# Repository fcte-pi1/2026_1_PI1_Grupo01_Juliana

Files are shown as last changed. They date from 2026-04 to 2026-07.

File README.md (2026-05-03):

# 2026.1_PI1_Grupo1_Juliana

## 🐭 Projeto Integrador 1 – Micromouse Autônomo

Desenvolvimento de um robô autônomo do tipo Micromouse capaz de explorar e resolver labirintos de diferentes dimensões (4×4, 8×8 e 16×16). O projeto é desenvolvido por equipes multidisciplinares organizadas em quatro subgrupos: **Software**, **Eletrônica**, **Estrutura** e **Energia**.

A documentação técnica completa — incluindo escopo, cronograma, orçamento e diagramas — está disponível na pasta [docs/](https://github.com/fcte-pi1/2026_1_PI1_Grupo01_Juliana/tree/main/docs).

---

## 🧩 Visão Geral
O Micromouse é um robô de pequeno porte que navega de forma completamente autônoma por um labirinto, sem intervenção humana durante a execução. O sistema é composto por:

### 💻 Software
- Definição da arquitetura de software embarcado e web.
- Implementação do controle de locomoção (PID) e navegação autônoma nos 3 labirintos.
- Sistema web de telemetria com exibição em tempo real e histórico de corridas.

### 🔌 Eletrônica
- Seleção e integração de sensores e atuadores.  
- Desenvolvimento do esquemático e PCB.  
- Calibração e testes de circuitos.  

### 🔩 Estrutura
- Projeto do chassi e layout do veículo.  
- Montagem e fixações definitivas.  
- Integração física dos módulos de hardware e energia.  

### ⚡ Energia
- Análise de consumo energético.  
- Dimensionamento da bateria.  
- Validação com testes reais.  

---

## 📁 Estrutura do projeto
```
2026_1_PI1_Grupo01_Juliana/
│
├── docs/        # Documentação técnica, relatórios e diagramas
├── hw/          # Esquemáticos, PCB e arquivos de eletrônica
├── mec/         # Arquivos de CAD e projeto mecânico
├── src/         # Código-fonte do software embarcado e web
|
├── CONTRIBUTING.MD
└── README.md
```

---

## 🤝 Como Contribuir
Consulte o [CONTRIBUTING.md](https://github.com/fcte-pi1/2026_1_PI1_Grupo01_Juliana/blob/docs/contributing/CONTRIBUTING.MD) para diretrizes de contribuição, padrão de branches, commits e pull requests.

---

## 👥 Equipe
### 💻 Software

<table>
  <tr>
    <td align="center">
      <a href="https://github.com/GuilhermeB12">
        Nome<br/>
        <b>Guilherme Brito</b>
      </a>
    </td>
    <td align="center">
      <a href="https://github.com/GustavoHenriqueRS">
        Nome<br/>
        <b>Gustavo Henrique</b>
      </a>
    </td>
    <td align="center">
      <a href="https://github.com/manu-sgc">
        Nome<br/>
        <b>Manoela Silvestre</b>
      </a>
    </td>
    <td align="center">
      <a href="https://github.com/thaleseuflauzino">
        Nome<br/>
        <b>Thales Henrique (Subgerente)</b>
      </a>
    </td>
    <td align="center">
      <a href="https://github.com/VHbernardes">
        Nome<br/>
        <b>Victor Hugo Bernardes</b>
      </a>
    </td>
  </tr>
</table>

### 🔌 Eletrônica

<table>
  <tr>
    <td align="center">
      <a href="https://github.com/sidts">
        Nome<br/>
        <b>Enrico Martins</b>
      </a>
    </td>
    <td align="center">
      <a href="https://github.com/liman-ia">
        Nome<br/>
        <b>Ian Lima (Subgerente)</b>
      </a>
    </td>
    <td align="center">
      <a href="https://github.com/EuAmoMilho">
        Nome<br/>
        <b>Noboru Watanabe</b>
      </a>
    </td>
    <td align="center">
      <a href="https://github.com/pLopess">
        Nome<br/>
        <b>Pedro Lopes</b>
      </a>
    </td>
    <td align="center">
      <a href="https://github.com/pedrolucasdourado">
        Nome<br/>
        <b>Pedro Lucas Dourado</b>
      </a>
    </td>
  </tr>
</table>

### 🔩 Estrutura

<table>
  <tr>
    <td align="center">
      <a href="https://github.com/arther-garthur">
        Nome<br/>
        <b>Arthur Porto (Subgerente)</b>
      </a>
    </td>
    <td align="center">
      <a href="https://github.com/manuvaladares">
        Nome<br/>
        <b>Manuella Valadares</b>
      </a>
    </td>
    <td align="center">
      <a href="https://github.com/devMarcosVM">
        Nome<br/>
        <b>Marcos Vieira Marinho</b>
      </a>
    </td>
    <td align="center">
      <a href="https://github.com/mat054">
        Nome<br/>
        <b>Mateus Castro</b>
      </a>
    </td>
    <td align="center">
      <a href="https://github.com/otamv4">
        Nome<br/>
        <b>Otávio Melchíades</b>
      </a>
    </td>
  </tr>
</table>

### ⚡ Energia

<table>
  <tr>
    <td align="center">
      <a href="https://github.com/andre-maia51">
        Nome<br/>
        <b>André Maia (Gerente Geral)</b>
      </a>
    </td>
    <td align="center">
      <a href="https://github.com/davi-aguiar-vieira">
        Nome<br/>
        <b>Davi Aguiar</b>
      </a>
    </td>
    <td align="center">
      <a href="https://github.com/fbressa">
        Nome<br/>
        <b>Filipe Bressanelli</b>
      </a>
    </td>
    <td align="center">
      <a href="https://github.com/lueewts">
        Nome<br/>
        <b>Melissa Santos(Sub-gerente)</b>
      </a>
    </td>
  </tr>
</table>

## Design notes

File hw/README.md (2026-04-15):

# _Hardware_

Esta pasta deverá armazenar arquivos referentes a:

- Simulações de circuitos eletrônicos (alimentação, sensores, atuadores etc.): [Qucs](https://qucs.sourceforge.net/), [QSPICE](https://www.qorvo.com/design-hub/design-tools/interactive/qspice), [Fritzing](https://fritzing.org/), dentre outros.
- Esquemáticos de circuitos: [KiCad](https://www.kicad.org/), Qucs, QSPICE.
- Diagramas de bloco: [Canva](https://www.canva.com/pt_br/), [TikZ](https://tikz.net/).
- _Datasheets_ de componentes eletrônicos, microcontroladores, _shields_ Arduino, motores etc.
- Testes tabelados de circuitos: arquivos CSV, Excel.
- Imagens PNG e JPEG de resultados práticos: fotos de testes reais, gráficos de resultados etc.
- Outros arquivos referentes ao _hardware_ do projeto.

> [!WARNING]
> **Não acrescente código-fonte a esta pasta.** O código desenvolvido para microcontroladores e SOCs ([Arduino](https://www.arduino.cc/), [ESP32](https://www.espressif.com/), [Raspberry Pi](https://www.raspberrypi.com/)) deverá ser armazenado na pasta [src/firmware](https://github.com/fcte-pi1/template/tree/main/src/firmware) deste repositório.

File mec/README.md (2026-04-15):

# _Mecânica e Estruturas_

Esta pasta deverá ser utilizada para armazenar arquivos relativos ao projeto estrutural, mecanismos, materiais, estudos aerodinâmicos, equações dinâmicas, construção e manufatura, impressão 3D, e correlatos.

Os arquivos a serem incluídos, são, dentre outros:
- Arquivos CAD de peças e montagens (FCStd, STEP, etc). 
- Desenhos técnicos (pdf, etc).
- Arquivos de impressão 3D (STL, etc).
- Imagens rasterizadas e vetorizadas (eps, pdf, svg, etc).
- Documentos e estudos realizados para o projeto (markdown, LaTeX, etc).

Durante o projeto, os grupos são encorajados a realizarem estudos para o projeto de estruturas, mecanismos, aerodinamica, dentre outros, e muitos desses estudos não caberão no relatório a ser entregue. Esses estudos podem ser colocados também nessa pasta, preferencialmente utilizando markdown (.md) para facilitar a leitura em ambiente web. Lembre-se que você pode utilizar equações em formato LaTeX no markdown e não deixe de utilizar links para o material de referencia que utilizaram. Estudos bem realizados contarão de maneira positiva na avaliação das equipes, porém lembre-se que não é permitida a utilização de IA, e que esse material deve ser principalmente útil à equipe.

> [!WARNING]
> Não acrecente arquivos da parte de hardware eletrônico aqui, como arquivos de KiCAD. Estes devem ser salvos na pasta [hw](https://github.com/fcte-pi1/template/tree/main/hw) deste repositório.

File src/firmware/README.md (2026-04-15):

# _Firmware_
Esta pasta deverá armazenar arquivos referentes a:

- Código-fonte para microcontroladores e SOCs: [Arduino](https://www.arduino.cc/), [ESP32](https://www.espressif.com/), [Raspberry Pi](https://www.raspberrypi.com/), dentre outros.
- Projetos de organização destes códigos, caso utilize IDEs: [Arduino IDE](https://www.arduino.cc/en/software/), [Visual Studio](https://visualstudio.microsoft.com/pt-br/downloads/) etc.
- Arquivos de configuração: ```CMakeLists.txt``` se for usar [CMake](https://cmake.org/download/), ```Makefile``` se for usar [make](https://www.cs.colby.edu/maxwell/courses/tutorials/maketutor/) etc.

Evite incluir:
- Artefatos de compilação: os arquivos de saída compilados (binários, arquivos objeto, .hex, .elf) devem ser gerados pelo processo de compilação e não incluídos no repositório.
- Arquivos temporários/específicos do sistema operacional: Arquivos como .DS_Store (macOS) ou arquivos de configuração do editor (a menos que esteja usando uma configuração compartilhada como .editorconfig).
- Configurações pessoais: Arquivos de configuração locais específicos da máquina do desenvolvedor.

> [!WARNING]
> **Não acrescente arquivos referentes a _hardware_ nesta pasta.** Eles deverão ser armazenados na pasta [hw](https://github.com/fcte-pi1/template/tree/main/hw) deste repositório.

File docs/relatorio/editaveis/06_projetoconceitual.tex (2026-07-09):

\chapter{Projeto Conceitual do Produto}

\section{Características gerais}

O projeto tem como foco o desenvolvimento de um robô autônomo capaz de mapear e solucionar labirintos desconhecidos de dimensões 4x4 e 8x8 células no menor tempo possível. O sistema integra um chassi, hardware de controle baseado em ESP32, algoritmos de navegação e um sistema web para transmissão de telemetria em tempo real. A seguir, a figura \ref{fig:eap_micromouse} representa a EAP do projeto que detalha a subdivisão de pacotes de trabalho nas frentes de Estrutura, Hardware, Energia e Software.

\begin{landscape}
    \begin{figure}[htpb]
        \centering
        
        \caption{Estrutura Analítica do Projeto (EAP).}
        \label{fig:eap_micromouse}
    \end{figure}
\end{landscape}

% \textcolor{red}{Descrever produto de forma geral. Apresentar itens teóricos sobre o projeto a serem aprofundados ou detalhados oportunamente.}

% \textcolor{red}{Apresentar e explicar a Estrutura Analítica do Projeto (EAP), tomando cuidado com a legibilidade da imagem. Se necessário, coloque a EAP dentro do comando ``\textsf{\textbackslash begin\{landscape\} \textbackslash end\{landscape\}}'' para que ela seja apresentada em uma página deitada.}

\section{Estrutura}

O desenvolvimento do \textit{micromouse} depende intimamente do seu projeto estrutural físico. A área de estruturas é fundamental para garantir a integridade, o desempenho de locomoção e a correta acomodação dos sistemas eletrônicos. Caberá a essa frente de trabalho tanto a concepção e modelagem em CAD de um chassi resistente e leve (fabricado em impressão 3D), quanto o planejamento e construção precisa do labirinto modular em madeira, ambiente sem o qual a validação e repetibilidade dos algoritmos de navegação seriam impossíveis.

Esta seção detalha os
critérios de dimensionamento, a escolha de materiais e as decisões de
projeto que orientaram os modelos em CAD.

\subsection{Chassi do \textit{Micromouse}}

O chassi foi projetado para abrigar os componentes eletrônicos e mecânicos do \textit{micromouse} dentro do limite dimensional estipulado pelas regras da competição, priorizando distribuição de massa equilibrada, proteção dos componentes e facilidade de manutenção.

\subsubsection{Primeiro Protótipo}

O primeiro protótipo adotou geometria triangular para o chassi, com comprimento de 152\,mm e largura de 160\,mm. A estrutura possui altura de 15\,mm (sem componentes montados), distância entre eixos de 162\,mm e rodas de 68\,mm de diâmetro por 26\,mm de largura. Detalhes da prancha técnica estão especificados na Figura \ref{fig:chassi_draw_v1} no Apêndice \ref{apendice_cad_chassi}.
\begin{figure}[htbp]
    \centering
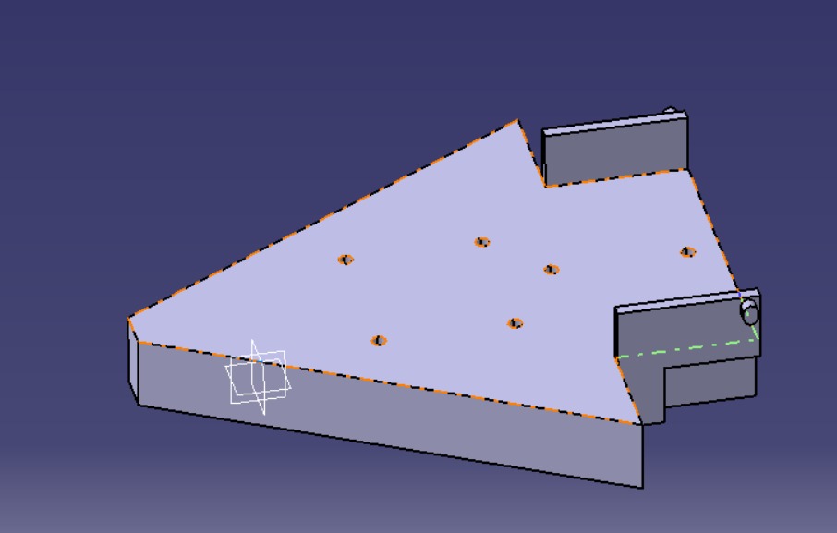
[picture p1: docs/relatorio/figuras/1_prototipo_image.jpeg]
    
    \caption{Modelo CAD do primeiro protótipo do chassi}
    \label{fig:chassi_cad_v1}
\end{figure}

\begin{table}[htbp]
\centering
\caption{Dimensões principais do chassi — Primeiro Protótipo.}
\label{tab:dimensoes_chassi_v1}
\begin{tabular}{lcc}
    \hline
    \textbf{Cota / Elemento}       & \textbf{Valor (mm)} & \textbf{Observação}    \\ \hline
    Comprimento total              & 152                 & Limite máx. 180\,mm    \\
    Largura total                  & 160                 & Limite máx. 180\,mm    \\
    Altura total (sem componentes) & 15                  &                        \\
    Distância entre eixos          & 162                 &                        \\
    Diâmetro da roda               & 68                  &                        \\
    Largura da roda                & 26                  &                        \\
    \hline
\end{tabular}
\end{table}

\FloatBarrier 

\subsubsection{Segundo Protótipo}

Com base nas limitações identificadas no primeiro protótipo, desenvolveu-se uma versão revisada com estrutura em dois andares. O primeiro andar (peça \textit{chassi}, 0{,}06\,kg) acomoda os motores, a bateria e os sensores IR, com largura frontal de 170\,mm, altura de 15{,}8\,mm e raio traseiro de 53{,}12\,mm. O segundo andar (peça \textit{2andar}, 0{,}08\,kg) abriga o ESP32, o driver de motor e os módulos eletrônicos auxiliares, com largura de 92\,mm e altura de 78{,}8\,mm. Essa separação melhora a organização do cabeamento, facilita a manutenção e reduz interferências entre os subsistemas de potência e controle.
Detalhes da prancha técnica estão especificados nas Figura \ref{fig:chassi_draw_1andar} e Figura \ref{fig:chassi_draw_2andar} no Apêndice \ref{apendice_cad_chassi}.

\begin{figure}[htbp]
    \centering
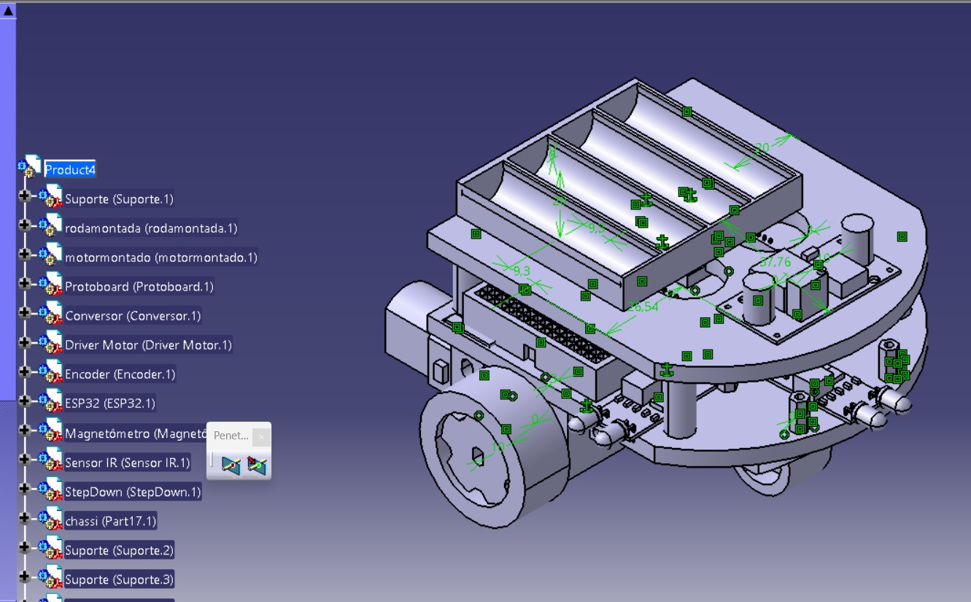
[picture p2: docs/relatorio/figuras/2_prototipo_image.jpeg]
    
    \caption{Modelo CAD do segundo protótipo com estrutura em dois andares, evidenciando a disposição dos componentes eletrônicos e mecânicos.}
    \label{fig:chassi_cad_v2}
\end{figure}

\FloatBarrier 

\subsubsection{Justificativa do Material — PLA}

O PLA (\textit{Polylactic Acid}) foi selecionado como material de
fabricação do chassi pelos seguintes motivos, considerando suas propriedades mecânicas e estabilidade dimensional \cite{farah2016pla_review}:

\begin{itemize}
    \item \textbf{Relação peso/resistência:}
          O PLA apresenta estabilidade dimensional e resistência aos esforços mecânicos exigidos. Graças à sua rigidez estrutural, suporta impactos imprevistos contra paredes no labirinto fornecendo uma estrutura confiável ao mesmo tempo em que possui baixa densidade, o que não prejudica a aceleração dos motores.

    \item \textbf{Processabilidade por impressão 3D (FDM):}
          Ao contrário do ABS, o PLA requer menores temperaturas de extrusão e não precisa de cabine fechada, evitando falhas por \textit{warp} (empenamento) e favorecendo a obtenção de peças com melhor repetibilidade dimensional em aplicações de prototipagem; além disso, trata-se de um material amplamente empregado em processos de manufatura aditiva por FDM \cite{sandanamsamy2022fdm_pla}.

    \item \textbf{Custo e disponibilidade:}
          Pela sua ampla adoção técnica, o PLA é uma opção de custo acessível de prototipagem, sendo amplamente disponível para rápida compra e uso nos laboratórios da instituição.

    \item \textbf{Limitações conhecidas e mitigações adotadas:}
          Embora o PLA exiba amolecimento sob elevadas temperaturas (perto de $60^{\circ}\text{C}$), a condição operacional do robô em competições \textit{indoor} e os tempos curtos de percurso não expõem o chassi a esse perigo. O fluxo de ar interno na execução afasta os componentes elétricos da temperatura prejudicial.
\end{itemize}

% ------------------------------------------------------------------
% TEXTO — Roteiro de testes estruturais do chassi (para PC2)
% Liste os testes que serão realizados para validar a estrutura.
% ------------------------------------------------------------------

% \subsubsection*{Roteiro de Testes — Chassi}

% \begin{table}[htbp]
%     \centering
%     \caption{Roteiro de testes de verificação e validação da estrutura do chassi.}
%     \label{tab:testes_chassi}
%     \begin{tabular}{p{1.2cm} p{3cm} p{4.5cm} p{4cm}}
%         \hline
%         \textbf{Código} & \textbf{Nome do teste} & \textbf{Procedimento} & \textbf{Resultado esperado} \\ \hline
%         TE-C01 & Verificação dimensional &
%             Medir comprimento e largura do chassi impresso com paquímetro. &
%             Valores ≤ 250 mm em ambas as dimensões. \\ \hline
%         TE-C02 & Teste de encaixe dos componentes &
%             Montar todos os subsistemas no chassi e verificar folgas. &
%             Nenhum componente solto ou com interferência. \\ \hline
%         TE-C03 & % >>> nome do teste <<< &
%             % >>> procedimento <<< &
%             % >>> resultado esperado <<< \\ \hline
%         % Adicione linhas conforme necessário
%         \hline
%     \end{tabular}
% \end{table}

% \subsection{Labirinto Modular de Testes (4×4)}

% O labirinto de testes 4×4 foi projetado para simular o ambiente rigoroso da competição, permitindo a calibração de sensores e o aprimoramento do algoritmo de navegação do robô. 
% Trata-se de um ambiente físico que reproduz fielmente as medidas e características oficiais do torneio: malhas de células quadradas com $18\text{ cm}$ de lado cada, delimitadas por paredes de
%  $5\text{ cm}$ de altura por $1,2\text{ cm}$ de espessura. Visualmente, o labirinto adota o padrão da categoria, com piso fosco na cor preta, paredes brancas com ótima refletividade para o sensoriamento
%   \textit{infravermelho} e topos pintados na cor vermelha, criando um contraste e respeitando o regulamento. 

% \begin{figure}[htbp]
%     \centering
%     \includegraphics[width=0.8\linewidth]{figuras/visao_geral.jpeg}
%     \caption{Labirinto modular 4×4 de testes. Dimensões externas:
%              72 cm × 72 cm. Paredes brancas com topos vermelhos;
%              piso preto.}
%     \label{fig:labirinto_completo}
% \end{figure}

% % ------------------------------------------------------------------
% % FIGURA — Detalhe do sistema de encaixe entre módulos
% % ------------------------------------------------------------------

% % \begin{figure}[htbp]
% %     \centering
% %     \includegraphics[width=0.8\linewidth]{figuras/labirinto_encaixe}
% %     \caption{Detalhe do sistema de encaixe entre os módulos de parede.
% %              A folga projetada (tipicamente na ordem de 0,3 a 0,5 mm) garante montagem sem ferramentas
% %              e desmontagem rápida para reconfiguração do labirinto.}
% %     \label{fig:labirinto_encaixe}
% % \end{figure}

% \begin{table}[htbp]
%     \centering
%     \caption{Dimensões do labirinto de testes e correspondência com
%              as regras da competição.}
%     \label{tab:dimensoes_labirinto}
%     \begin{tabular}{lccc}
%         \hline
%         \textbf{Parâmetro}            & \textbf{Regra (competição)} & \textbf{Projetado} & \textbf{Tolerância} \\ \hline
%         Lado da célula                & 180 mm                       & 180 mm              & ±0 mm              \\
%         Altura da parede              & 50 mm                        & 50 mm              & ±0 mm              \\
%         Espessura da parede           & 12 mm                        & 12 mm              & ±0 mm              \\
%         Dimensão total do labirinto   & 720 mm × 720 mm              & 720 mm × 720 mm     & ±0 mm              \\
%         \hline
%     \end{tabular}
% \end{table}

% \subsubsection{Decisões de Modularidade}

% O projeto do labirinto foi concebido com foco na modularidade, permitindo a rápida construção e reconfiguração de diversos
% cenários para testes. Para isso, cada parede de cada célula foi fabricada como uma peça individual, dispondo de um sistema de encaixe (\textit{press-fit} ou por pinos/ranhuras) direto nos módulos de chão.

% A espessura de $12\text{ mm}$ adotada para as paredes, além de respeitar as dimensões da competição, é essencial para transferir rigidez à estrutura de cada módulo.

% Essa abordagem de separação célula a célula oferece total liberdade na criação dos trajetos. A constante possibilidade de reconfigurar o layout do labirinto atende à necessidade da equipe de software de validar diferentes hipóteses para os algoritmos de mapeamento e navegação de maneira fácil. Ao finalizar os testes, a desmontagem resulta em peças de pequeno porte, garantindo total facilidade de transporte e armazenamento compacto do projeto.

% \subsubsection{Justificativa do Material — Madeira (MDF)}

% O material selecionado para as paredes e base do labirinto de testes
% foi o \textbf{MDF (\textit{Medium Density Fiberboard})} de $12\text{ mm}$ e $6\text{ mm}$ pelos seguintes motivos, com forte apelo às decisões de modularidade do projeto:

% \begin{itemize}
%     \item \textbf{Baixo custo e disponibilidade:}
%           O MDF é facilmente encontrado em qualquer marcenaria ou móveis não utilizados, possuindo um custo-benefício excelente para a construção de dezenas de módulos de parede idênticos, viabilizando o projeto de um labirinto versátil.

%     \item \textbf{Rigidez e estabilidade dimensional:}
%           Sendo um painel de fibras de média densidade, ele não apresenta veios direcionais como a madeira maciça ou compensado, o que favorece um comportamento estrutural mais uniforme e compatível com aplicações que exigem rigidez e resistência mecânica \cite{sliseris2014mdf_strength}.

%     \item \textbf{Facilidade de fabricação e acabamento:}
%           Por possuir uma superfície lisa, o MDF permite um excelente acabamento em pintura (necessário para a leitura do sensor IR nas cores branco e vermelho). Além disso, é facilmente cortado e usinado com ferramentas comuns, facilitando a produção em série dos módulos de parede e chão.

%     \item \textbf{Massa e praticidade:}
%           Os blocos modulares em MDF possuem massa confortável para o manuseio rápido, visto que um dos focos da modularidade é permitir a rápida reconfiguração.
% \end{itemize}

% \subsubsection{Acabamento Superficial}

% Para satisfazer o regulamento, está previsto que as faces laterais das paredes modulares recebam pintura em esmalte ou tinta acrílica branca, garantindo reflectância para os emissores infravermelhos. O topo das paredes deverá ser pintado de vermelho, demarcando visualmente os limites. Por fim, planeja-se que o tabuleiro (piso) principal receba um acabamento em preto fosco para absorver a radiação IR, de modo a criar o contraste de leitura adequado aos sensores descendentes (quando presentes) e mitigar o espalhamento de luz horizontal.

% ------------------------------------------------------------------
% TEXTO — Roteiro de testes do labirinto (para PC2)
% ------------------------------------------------------------------

% \subsubsection*{Roteiro de Testes — Labirinto}

% \begin{table}[htbp]
%     \centering
%     \caption{Roteiro de testes de verificação e validação do labirinto modular.}
%     \label{tab:testes_labirinto}
%     \begin{tabular}{p{1.2cm} p{3cm} p{4.5cm} p{4cm}}
%         \hline
%         \textbf{Código} & \textbf{Nome do teste} & \textbf{Procedimento} & \textbf{Resultado esperado} \\ \hline
%         TE-L01 & Verificação dimensional das células &
%             Medir o lado interno de cada célula com trena. &
%             Valor entre ??? mm e ??? mm (tolerância ±??? mm). \\ \hline
%         TE-L02 & Estabilidade das paredes &
%             Empurrar a parede com força de ??? N e verificar deslocamento. &
%             Deslocamento ≤ ??? mm; parede retorna à posição original. \\ \hline
%         TE-L03 & Reconfiguração do layout &
%             Desmontar e remontar o labirinto em configuração diferente. &
%             Montagem concluída em menos de ??? minutos sem ferramentas. \\ \hline
%         TE-L04 & % >>> nome do teste <<< &
%             % >>> procedimento <<< &
%             % >>> resultado esperado <<< \\ \hline
%         \hline
%     \end{tabular}
% \end{table}

\section{Descrição de \textit{hardware}}

\subsection{Diagrama de Blocos}

O diagrama de blocos consiste em uma representação visual de alto nível dos principais módulos e interações do sistema embarcado do \textit{micromouse}, conforme ilustrado na Figura \ref{fig:diag_hw}.

\begin{figure}[H]
    \centering
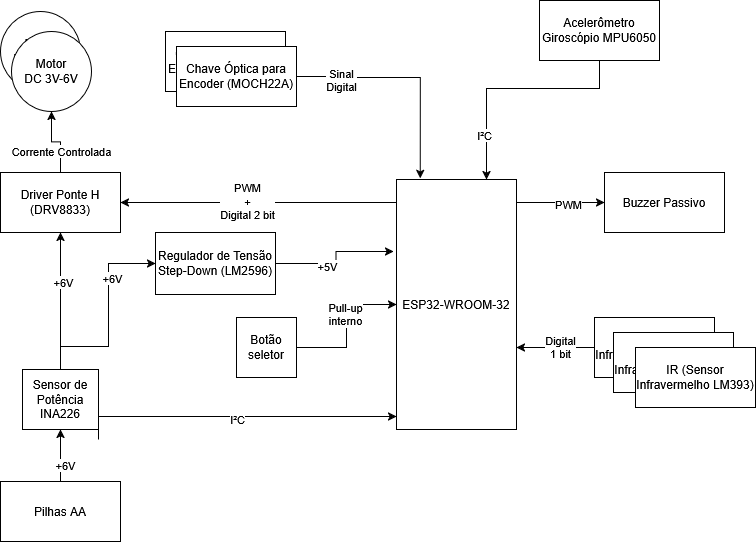
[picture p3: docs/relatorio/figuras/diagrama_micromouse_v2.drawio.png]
    
    \caption{Diagrama de blocos dos componentes eletrônicos do \textit{micromouse}}
    \label{fig:diag_hw}
\end{figure}

\subsection{Esquematico}

O projeto esquemático detalha as conexões físicas entre todos os componentes eletrônicos do robô. Para facilitar a visualização e o entendimento, a representação do circuito foi subdividida em módulos, apresentados através das Figuras no \autoref{apendice_esquematicos_hw}.

\subsection{Justificativa da escolha dos componentes de \textit{hardware}}
\label{sec:justificativa-componentes}

Esta seção apresenta a justificativa técnica para a seleção de cada componente utilizado no projeto, considerando requisitos funcionais, disponibilidade, custo e compatibilidade com a arquitetura geral do sistema.

\begin{itemize}

    \item \textbf{ESP32-WROOM-32:} O ESP32-WROOM-32 foi selecionado por sua capacidade de processamento, integração nativa Wi-Fi/Bluetooth e operação em 3,3 V. Destaca-se pelo baixo custo e alta compatibilidade com sistemas robóticos e componentes eletrônicos modernos \cite{oliveira2024_esp32_roboticar}.

    \item \textbf{Sensor Infravermelho (LM393):} Adotado para a detecção de paredes, o sensor LM393 oferece retorno digital ao microcontrolador, baixo consumo elétrico (<1 mA) e alcance de 2 a 30 cm. É uma solução econômica e de baixa complexidade ideal para projetos educacionais \cite{lima2025_micromouse_lm393}.

%   \item \textbf{Bússola Magnetômetro (GY-271 HMC5883L):} O módulo GY-271 atua na identificação da orientação absoluta do robô e correção de desvios após manobras de 90\textdegree\ e 180\textdegree. Requer testes de interferência eletromagnética em relação aos motores para garantir a estabilidade das leituras via I\textsuperscript{2}C \cite{eletrogate_bussola}.

    \item \textbf{Giroscópio e Acelerômetro (MPU6050):} O MPU6050 identifica a orientação relativa do robô, atuando via I\textsuperscript{2}C como redundância à odometria para mitigar desvios de trajetória durante as curvas. Destaca-se pelo tamanho compacto e baixo consumo energético.

    \item \textbf{Driver Ponte H (DRV8833):} O DRV8833 controla de forma independente a velocidade e a direção dos dois motores DC via sinais PWM. É compacto, eficiente e possui proteções internas essenciais contra sobrecorrente e superaquecimento \cite{oliveira2024_esp32_roboticar}.

    \item \textbf{Conversor Analógico-Digital (ADS1115):} O conversor externo ADS1115 (16 bits) foi escolhido para contornar o ruído intrínseco do ADC interno do ESP32 gerado pelo uso do Wi-Fi. Ele garante leituras consistentes e precisas para os sensores analógicos de corrente e tensão do projeto \cite{makerhero_ads1115, embarcados_esp32_adc}.

    \item \textbf{Regulador de Tensão Step-Down (LM2596):} O módulo LM2596 atua na conversão eficiente da tensão fornecida pela bateria. Ele garante uma alimentação contínua e estável para os componentes lógicos, protegendo o sistema embarcado contra oscilações elétricas \cite{oliveira2024_esp32_roboticar}.

    \item \textbf{Sensor de Tensão 0--25V (FZ0430):} O sensor FZ0430 monitora o nível da bateria, atuando como um divisor de tensão capaz de medir até 25 V. Condicionado pelo ADS1115, permite ao sistema calcular a carga com alta precisão e disparar alertas preventivos de bateria baixa \cite{valdovinos2019instrumentacion}.

    \item \textbf{Chave Óptica para Encoder (MOCH22A):} O MOCH22A lê os pulsos dos discos acoplados aos motores, fornecendo a odometria necessária para calcular o deslocamento e a rotação do Micromouse \cite{petercorke}. Sua integração via interrupções digitais no ESP32 possui baixo custo e montagem simples \cite{makerhero_moch22a}.

    \item \textbf{Sensor de Corrente (ACS712):} Utilizando o efeito Hall, a versão de 5A do ACS712 monitora o consumo elétrico dos circuitos de potência. Aliado ao conversor ADS1115, possibilita calcular a potência instantânea e estimar em tempo real a autonomia da bateria para a telemetria \cite{valdovinos2019instrumentacion}.

    \item \textbf{Buzzer Passivo:} O \textit{buzzer} passivo realiza a sinalização sonora de eventos do robô. Foi priorizado frente à versão ativa por possuir dimensões mais compactas, ser mais leve e exigir um esquema de acionamento eletrônico de menor custo \cite{makerhero_buzzer}.

\end{itemize}

% \textcolor{red}{A descrição de \textit{hardware} no documento deve permitir que outras pessoas repliquem o produto proposto neste documento. Para isso, deve-se explicar de forma textual os principais sub-sistemas e as escolhas de projeto, além de indicar:}

% \begin{itemize}
%     \item \textcolor{red}{ O diagrama de blocos \cite{blockdiagram}, que oferece uma visão geral do hardware, com as principais partes do sistema e as ligações entre elas.}
%     %\item A lista de materiais \cite{bom}, que facilita a montagem do sistema, indicando tudo que deve ser adquirido. Aproveitem a lista de materiais para apresentarem o orçamento dos mesmos.
%     \item \textcolor{red}{ O esquemático \cite{esquematico}, que mostra as conexões elétricas entre os componentes. Deve-se indicar os componentes por nomes e símbolos, e as conexões entre eles, incluindo a pinagem dos componentes. Se o esquemático ficar muito grande, pode-se separa-lo em vários esquemáticos. A ligação em \textit{protoboard} não é considerada um esquemático adequado.}
% \end{itemize}

% \textcolor{red}{A Fig. \ref{fig:diagrama_blocos_e_esquematico} apresenta o diagrama de blocos e o esquemático de um circuito conversor de corrente alternada para corrente direta, a título de exemplo. Repare que o diagrama de blocos indica os subsistemas do circuito completo apresentado no esquemático.
% % Comecem com o diagrama de blocos, que é mais genérico, e depois indiquem os detalhes com a lista de materiais e os esquemáticos.
% }

% \begin{figure}[htbp]
%     \centering
%     \includegraphics[width=0.5\linewidth]{figuras/Exemplo-diagrama-de-blocos.png}
%     \includegraphics[width=0.5\linewidth]{figuras/Esquematico.png}
%     \caption{\textcolor{red}{Diagrama de blocos e esquemático de um circuito conversor de corrente alternada para corrente direta. Extraído de \cite{block_n_schematic}.}}
%     \label{fig:diagrama_blocos_e_esquematico}
% \end{figure}

\section{Análise de consumo energético}

O subgrupo de Energia é responsável por garantir a alimentação elétrica do micromouse. O trabalho foca em fornecer energia estável para os motores, sensores e o microcontrolador ESP32.

O grupo realiza o cálculo do gasto energético de cada componente, seleciona a fonte de alimentação (bateria ou pilhas) e projeta os circuitos de regulação de tensão. Além disso, o sistema deve permitir o monitoramento do nível de carga para que o dado seja enviado via telemetria.

\subsection{Frentes de trabalho}
As atividades estão divididas em:
\begin{itemize}
    \item \textbf{Dimensionamento:} Cálculo da corrente e energia total (Joules e Watt-hora).
    \item \textbf{Regulação de Tensão:} Conversão da tensão da fonte (7.2V) para os níveis de operação (5V e 3.3V).
    \item \textbf{Proteção e Segurança:} Gestão térmica e prevenção de danos por picos de corrente.
    \item \textbf{Monitoramento:} Implementação de divisor de tensão para leitura analógica da carga.
\end{itemize}

\subsection{Identificação dos subsistemas elétricos}
Após consulta das datasheets de cada um dos componentes, foram obtidos os seguintes dados de tensão e de corrente estimadas, organizados na seguinte tabela:

\begin{table}[h]
\centering
\renewcommand{\arraystretch}{1.3} % Aumenta um pouco o espaçamento das linhas para melhor leitura
\resizebox{\textwidth}{!}{%
\begin{tabular}{|l|c|c|}
\hline
\textbf{Componente} & \textbf{Tensão de Operação (V)} & \textbf{Corrente Estimada (mA)} \\ \hline
ESP32 (Wi-Fi e Bluetooth)       & 3.3 - 3.6     & 500           \\ \hline
02 Motores DC (Redução 48:1)    & 3.0 - 6.0     & 800-1000      \\ \hline
Driver Duplo Ponte H (DRV8833)  & 2.7 - 10.8    & 3             \\ \hline
Sensor IR (KY-032)              & 3.3 - 5.0     & 20            \\ \hline
Sensor Óptico ToF (VL53L0X)     & 3.3 - 5.0     & 20            \\ \hline
IMU (MPU6050 GY521)             & 3.3 - 5.0     & 5             \\ \hline
Mini Protoboard (170 pontos)    & -             & 0             \\ \hline\hline
\textbf{Total Necessário} & \textbf{5.0 (Fonte Principal)} & \textbf{$\approx$ 1050} \\ \hline
\end{tabular}}
\caption{Dimensionamento de Tensão e Corrente dos Componentes do Robô}
\label{tab:dimensionamento_energia}
\end{table}

\subsection{Cálculo da energia consumida por componente}
Para o cálculo da energia consumida por componente, foi utilizada a fórmula:
\[
    \ E = V (Volts) \cdot I (A) \cdot \Delta t (s)      [J]
\]

\begin{table}[h!]
\centering
\renewcommand{\arraystretch}{1.3}
\resizebox{\textwidth}{!}{%
\begin{tabular}{|l|c|c|c|c|}
\hline
\textbf{Componente} & \textbf{V (Volts)} & \textbf{I (Ampères)} & \textbf{t (Segundos)} & \textbf{E (Joules)} \\ \hline
ESP32 (Wi-Fi e Bluetooth)           & 3.3 & 0.500 & 1800 & 2970.0   \\ \hline
02 Motores DC (Redução 48:1)        & 5.0 & 1.000 & 1800 & 9000.0   \\ \hline
Driver Duplo Ponte H (DRV8833)      & 5.0 & 0.003 & 1800 & 27.0     \\ \hline
Sensor IR (KY-032)                  & 3.3 & 0.020 & 1800 & 118.8    \\ \hline
Sensor Óptico ToF (VL53L0X)         & 3.3 & 0.020 & 1800 & 118.8    \\ \hline
IMU (MPU6050 GY521)                 & 3.3 & 0.005 & 1800 & 29.7     \\ \hline\hline
\textbf{Total Estimado} & \textbf{-} & \textbf{-} & \textbf{1800} & \textbf{12264.3} \\ \hline
\end{tabular}}
\caption{Cálculo da Energia Consumida (Autonomia de 30 minutos com valores de pico)}
\label{tab:energia_componentes_pico}
\end{table}

\subsection{Escolha da fonte de alimentação}
\subsection*{Conversão para Watt-hora}
A partir do cálculo de consumo total do sistema para uma autonomia de aproximadamente 30 minutos, obtivemos uma energia consumida de 8700,3 J. Utilizando a relação de conversão de que 1 Wh=3600 J, temos:
\[
    \frac{12364,3 [J]}{3600} \approx 3,43 Wh
\]
\subsection*{Justificativas e Aplicação da Margem de Segurança}
É considerada boa prática utilizar uma margem de segurança de cerca de 20\% a 30\%. Essa margem é essencial por três motivos:
\begin{enumerate}
    \item \textbf{Corrente de Stall:} No momento em que o robô liga e arranca ou bate em uma parede e fica preso, os motores exigirão uma corrente maior.
    \item \textbf{Perdas térmicas e degradação da tensão:} À medida que a bateria descarrega, a tensão da mesma tende a cair, de modo a exigir mais corrente para manter a mesma potência, e também, o regulador de tensão interno da ESP32 dissipa parte da energia em forma de calor, pode ser uma quantidade insignificativa, porém, como as opções de bateria que serão apresentadas posteriormente estão na faixa mais baixa do limiar mínimo necessário, o grupo acha válido considerar uma margem de segurança mais generosa.
\end{enumerate}

Adotando uma margem de 20\%, o requisito de energia final passa a ser:
\[
    E = 3,43 \times 1,20 \approx 4,12 Wh
\]
 
Para suprir a demanda energética do projeto com margem de segurança (4,79 Wh), optou-se pela opção de alimentação por um banco de 6 pilhas AA recarregáveis (NiMH). Este arranjo fornece uma tensão nominal de 7.2V e capacidade média de 2000 mAh (totalizando cerca de 14,4 Wh), atendendo aos requisitos de energia e mantendo a estabilidade da tensão frente aos picos de corrente de tração. Outra opção viável seria a adaptação de um powerbank de 5V/2A, que já teria um circuito de estabilização de tensão.

\section{Descrição de \textit{software}}

O subgrupo de software é responsável por dois componentes principais e interdependentes: o \textbf{software embarcado}, executado no microcontrolador ESP32 do robô, e o \textbf{sistema web de telemetria}, responsável pela visualização e armazenamento dos dados de cada corrida.

\begin{center}
\includegraphics[
    width=0.8\textwidth,
    height=0.8\textheight,
    keepaspectratio
]{figuras/diagrama_atividades_uml.jpg}

\captionof{figure}{Diagrama de Atividades UML.}
\label{fig:diagramauml_fig}
\end{center}

O fluxo está dividido em três raias (\textit{swimlanes}): Operador/Usuário, Micromouse (ESP32) e Sistema Web. O processo começa com o operador posicionando o robô e disparando o início da corrida. A partir daí, uma barra de bifurcação (\textit{fork}) representa o paralelismo: o ESP32 inicializa seus sensores ao mesmo tempo que o sistema web abre a sessão de telemetria. Uma barra de junção (\textit{join}) sincroniza as duas trilhas antes do loop principal.

O ciclo de exploração repete: leitura dos sensores IR $\rightarrow$ detecção de paredes $\rightarrow$ atualização do mapa $\rightarrow$ algoritmo Flood Fill $\rightarrow$ movimentação. A cada passo, a telemetria é enviada ao sistema web em paralelo (velocidade, trajeto, bateria). Dois nós de decisão controlam a saída do loop: ``centro atingido?'' e ``bateria crítica?''. O alerta de bateria deriva para o operador e reintegra o fluxo. Ao atingir o centro, o robô calcula as estatísticas finais, envia ao sistema web, que persiste no banco e marca o campo ``Desafio cumprido''.

\subsection{Backlog do Produto}
 
O backlog foi elaborado com base nos requisitos funcionais (RF) e não funcionais (RNF) definidos no Capítulo 2, priorizados pela classificação MoSCoW.

\subsubsection{Histórias de Usuário (Requisitos Funcionais)}
 
\begin{itemize}

\item \textbf{HU01 – Resolução autônoma do labirinto} [\textit{Must have}]\\
\textit{Eu, como} avaliador do projeto, \textit{quero} que o sistema permita visualizar e validar a execução da resolução autônoma de labirintos de tamanhos 4×4, 8×8 e 16×16, \textit{para} verificar a capacidade de navegação sem intervenção humana.\\
\textbf{Critérios de aceitação:} o robô deve atingir o centro do labirinto sem tocar nas paredes e sem qualquer interação externa durante a tentativa. O protótipo desta interface pode ser visualizado na Figura \ref{fig:execucaoautonoma_fig} do Apêndice \ref{apendice_prototipos}.

\item \textbf{HU02 – Mapeamento incremental do labirinto} [\textit{Must have}]\\
\textit{Eu, como} desenvolvedor do sistema embarcado, \textit{quero} que o robô detecte e registre paredes à medida que explora, \textit{para} construir o mapa do labirinto em tempo de execução.\\
\textbf{Critérios de aceitação:} após a primeira corrida em um labirinto 4×4, ao menos 80\% das células devem ter sido corretamente mapeadas. O protótipo desta interface pode ser visualizado na Figura \ref{fig:mapeamento_fig} do Apêndice \ref{apendice_prototipos}.

\item \textbf{HU03 – Telemetria em tempo real} [\textit{Must have}]\\
\textit{Eu, como} observador da corrida, \textit{quero} visualizar no painel web o trajeto percorrido, o tempo, a velocidade média e o nível de bateria em tempo real, \textit{para} acompanhar o desempenho do robô durante a tentativa.\\
\textbf{Critérios de aceitação:} os dados devem ser atualizados no painel com latência máxima estipulada pela equipe, sem gargalos visuais perceptíveis. O protótipo desta interface pode ser visualizado na Figura \ref{fig:telemetria_fig} do Apêndice \ref{apendice_prototipos}.

\item \textbf{HU04 – Persistência e consulta de histórico} [\textit{Must have}]\\
\textit{Eu, como} professor avaliador, \textit{quero} consultar os resultados de corridas anteriores filtradas por labirinto, \textit{para} comparar o desempenho do robô ao longo do projeto.\\
\textbf{Critérios de aceitação:} os dados finais de cada corrida concluída devem ser gravados no banco de dados e recuperáveis pela interface de histórico com filtro por tamanho de labirinto. O protótipo desta interface pode ser visualizado na Figura \ref{fig:historicocorridas_fig} do Apêndice \ref{apendice_prototipos}.

\item \textbf{HU05 – Monitoramento de bateria} [\textit{Should have}]\\
\textit{Eu, como} operador do robô, \textit{quero} visualizar no painel web o nível percentual de carga da bateria enviado pelo sistema embarcado, \textit{para} evitar interrupções inesperadas durante as corridas.\\
\textbf{Critérios de aceitação:} o nível de bateria deve ser lido via divisor de tensão pelo ESP32 e exibido no painel web com atualização a cada ciclo de telemetria. O protótipo desta interface pode ser visualizado na Figura \ref{fig:monitoramentobateria_fig} do Apêndice \ref{apendice_prototipos}.

\item \textbf{HU06 – Indicador de desafio cumprido} [\textit{Could have}]\\
\textit{Eu, como} usuário do sistema web, \textit{quero} visualizar se o desafio foi cumprido (Sim/Não) ao término de cada corrida, \textit{para} identificar rapidamente o resultado no histórico.\\
\textbf{Critérios de aceitação:} ao final de cada corrida, o campo ``Desafio cumprido'' deve ser preenchido automaticamente com base na detecção da chegada ao centro. O protótipo desta interface pode ser visualizado na Figura \ref{fig:desafiocumprido_fig} do Apêndice \ref{apendice_prototipos}.
 
\end{itemize}
 
\subsection{Requisitos Não Funcionais}
 
\begin{itemize}
    \item \textbf{RNF01} [\textit{Must have}] – O código-fonte embarcado e a memória do labirinto não podem ser alterados durante a execução de uma tentativa na pista.
    \item \textbf{RNF02} [\textit{Must have}] – O sistema embarcado deve operar com o microcontrolador ESP32 como unidade central de processamento.
    \item \textbf{RNF03} [\textit{Must have}] – A latência da telemetria deve ser estipulada e estabilizada de modo que a atualização do painel ocorra sem gargalos perceptíveis em tempo real.
    \item \textbf{RNF04} [\textit{Must have}] – Nenhuma solução de software pronta pode substituir o desenvolvimento próprio dos módulos exigidos pelo escopo.
    \item \textbf{RNF05} [\textit{Should have}] – Cada \textit{issue} no GitHub deve ter no máximo dois responsáveis, garantindo rastreabilidade individual das contribuições.
    \item \textbf{RNF06} [\textit{Should have}] – Ferramentas de inteligência artificial generativa não podem ser utilizadas nas atividades avaliativas do subgrupo.
\end{itemize}

\subsection{Casos de Uso}

\begin{center}
\begin{longtable}{|l|c|p{5.5cm}|p{3cm}|c|}
\caption{Casos de uso funcionais -- Backlog do Micromouse.} \label{tab:backlog-uc} \\

\hline
\textbf{ID} & \textbf{HU orig.} & \textbf{Caso de uso} & \textbf{Atores} & \textbf{Prioridade} \\ \hline
\endfirsthead

\multicolumn{5}{c}%
{{\bfseries Tabela \thetable{} -- continuação da página anterior}} \\
\hline
\textbf{ID} & \textbf{HU orig.} & \textbf{Caso de uso} & \textbf{Atores} & \textbf{Prioridade} \\ \hline
\endhead

\hline \multicolumn{5}{|r|}{{Continua na próxima página...}} \\ \hline
\endfoot

\hline
\endlastfoot

\multicolumn{5}{|l|}{\textit{Módulo embarcado -- ESP32}} \\ \hline

UC01 & HU01 & Resolver labirinto autonomamente & Micromouse & Must have \\ \hline
UC02 & HU02 & Mapear labirinto incrementalmente & Micromouse & Must have \\ \hline
UC03 & HU02 & Ler sensores IR de distância & Micromouse & Must have \\ \hline
UC04 & HU01 & Executar algoritmo de navegação & Micromouse & Must have \\ \hline
UC05 & HU05 & Monitorar nível de bateria & Micromouse & Should have \\ \hline
UC06 & HU03 & Transmitir dados de telemetria & Micromouse & Must have \\ \hline
UC07 & HU01 & Registrar chegada ao centro & Micromouse & Must have \\ \hline
UC08 & HU01 & Calcular estatísticas finais & Micromouse & Must have \\ \hline

\multicolumn{5}{|l|}{\textit{Módulo web -- painel de telemetria}} \\ \hline

UC09 & HU03 & Visualizar telemetria & Operador, Avaliador & Must have \\ \hline
UC10 & HU05 & Exibir nível de bateria no painel & Operador & Should have \\ \hline
UC11 & HU04 & Consultar histórico de corridas & Operador, Avaliador & Must have \\ \hline
UC12 & HU04 & Filtrar histórico por tamanho de labirinto & Operador, Avaliador & Must have \\ \hline

\end{longtable}
\end{center}

\begin{center}
\includegraphics[
    width=0.8\textwidth,
    height=0.8\textheight,
    keepaspectratio
]{figuras/diagrama_caso_de_uso.jpg}
\captionof{figure}{Diagrama de Casos de Uso}
\label{fig:caso_de_uso_fig}
\end{center}

Os casos de uso foram agrupados por cor: em roxo os do firmware embarcado (UC01–UC08), em rosa os da plataforma web (UC09–UC12). Os três atores são o Avaliador, o Operador e o Micromouse/ESP32 (executa todos os UCs embarcados). Os relacionamentos «include» indicam dependências obrigatórias — por exemplo, UC01 sempre inclui UC02 (mapeamento). O «extend» entre UC11 e UC12 indica que filtrar por labirinto é um comportamento opcional dentro da consulta de histórico.

\subsection{BPMN}

\begin{center}
\includegraphics[
    width=0.8\textwidth,
    height=0.85\textheight,
    keepaspectratio
]{figuras/bpmn.png}

\captionof{figure}{Diagrama BPMN.}
\label{fig:bpmn_fig}
\end{center}

O diagrama BPMN representa o fluxo completo de execução do sistema Micromouse, desde o início da corrida até a visualização dos dados de telemetria. O modelo foi estruturado utilizando raias para separar as responsabilidades entre Usuário, Micromouse, Backend e Frontend.

O fluxo inicia com o operador posicionando o robô no labirinto e acionando o início da corrida. Em seguida, o Micromouse realiza a inicialização dos sensores e motores, enquanto o frontend inicia a sessão de telemetria. Após a sincronização das etapas iniciais, o robô entra no ciclo principal de exploração do labirinto.

Durante a execução, o ESP32 realiza continuamente a leitura dos sensores infravermelhos, detecta paredes, atualiza o mapa interno do labirinto e executa o algoritmo para definição do próximo movimento. Paralelamente, os dados de telemetria são enviados ao backend, incluindo posição, velocidade média, tempo de execução e nível de bateria.

O backend é responsável por processar os dados da corrida no banco de dados, enquanto o frontend web atualiza o painel de monitoramento em tempo real para o usuário. O fluxo permanece em repetição até que o robô atinja a chegada do labirinto.

Ao final da corrida, o sistema calcula as estatísticas finais, registra o resultado da tentativa e disponibiliza os dados históricos para consulta posterior através da plataforma web.

\subsection{Descrição da arquitetura da solução de \textit{software} proposta}

A arquitetura do sistema Micromouse foi concebida segundo o padrão em camadas (\textit{layered architecture}), que promove separação de responsabilidades, facilita a manutenção e permite a evolução independente de cada componente. A Fig.~\ref{fig:diagrama_arquitetura} apresenta o diagrama de arquitetura preliminar, evidenciando as cinco camadas principais: embarcada, comunicação, \textit{backend}, banco de dados e \textit{frontend} web.

\par
\begin{center}
\includegraphics[
    width=0.8\textwidth,
    height=0.85\textheight,
    keepaspectratio
]{figuras/diagrama_arquitetura.png}

\captionof{figure}{Diagrama de Arquitetura.}
\label{fig:diagrama_arquitetura}
\end{center}

\begin{center}
\small
\begin{longtable}{p{2.8cm}p{3.5cm}p{8.5cm}}
    \caption{Camadas, tecnologias e justificativas da arquitetura.}
    \label{tab:camadas_arquitetura} \\
    \toprule
    \textbf{Camada} & \textbf{Tecnologia} & \textbf{Justificativa Técnica} \\
    \midrule
    \endfirsthead

    \multicolumn{3}{c}%
    {{\bfseries Tabela \thetable{} -- continuação da página anterior}} \\
    \toprule
    \textbf{Camada} & \textbf{Tecnologia} & \textbf{Justificativa Técnica} \\
    \midrule
    \endhead

    \midrule \multicolumn{3}{r}{{Continua na próxima página...}} \\
    \endfoot

    \bottomrule
    \endlastfoot

    Embarcada & ESP32, ESP-IDF, FreeRTOS, C & O ESP32 oferece processamento dual-core, Wi-Fi integrado e baixo consumo energético, atendendo às restrições de um robô autônomo. O ESP-IDF é o \textit{framework} oficial da Espressif, com suporte nativo a periféricos, \textit{threads} (FreeRTOS) e pilha de rede. A linguagem C garante controle direto de \textit{hardware} e desempenho previsível, essencial para o algoritmo Flood Fill e o controle em tempo real dos motores. \\
    \midrule
    Comunicação & Wi-Fi 802.11b/g/n, MQTT / HTTP & O módulo Wi-Fi nativo do ESP32 elimina a necessidade de circuitos adicionais de comunicação. O protocolo MQTT foi escolhido para telemetria em tempo real por ser leve, orientado a eventos e com baixa latência sobre TCP. O broker MQTT recebe os dados do robô e os encaminha ao backend; o frontend consome esses dados via WebSocket para atualização em tempo real. Requisições HTTP/REST complementam para consultas de histórico e filtros. \\
    \midrule
    Backend & Python 3, FastAPI, Uvicorn & FastAPI é um \textit{framework} assíncrono de alta performance para APIs REST, com validação automática via Pydantic e documentação interativa (OpenAPI/Swagger). A escolha do Python acelera o desenvolvimento e integra-se naturalmente com bibliotecas de ciência de dados, caso seja necessária análise preditiva de desempenho. \\
    \midrule
    Banco de Dados & SQLite (dev) / PostgreSQL (prod), SQLAlchemy, Alembic & Banco relacional foi preferido pela consistência ACID e pelo modelo de dados bem estruturado (labirintos, corridas, telemetria). SQLite viabiliza protótipos rápidos sem infraestrutura; PostgreSQL pode ser adotado em produção para concorrência e volume elevado. SQLAlchemy (ORM) e Alembic (migrations) garantem portabilidade e versionamento do schema. \\
    \midrule
    Frontend Web & HTML5, CSS3, JavaScript (React em avaliação) & A camada de apresentação será desenvolvida como aplicação web responsiva, consumindo a API REST do backend para consultas de histórico e filtros, e WebSocket para telemetria em tempo real. A escolha inicial por tecnologias web puras reduz a curva de aprendizado; a adoção do React será avaliada conforme a evolução dos protótipos de interface. \\
\end{longtable}
\end{center}
\subsubsection{Visão Lógica.} O sistema é organizado em domínios bem definidos: (i) Navegação Autônoma, responsável pelo algoritmo Flood Fill, mapeamento de paredes e controle de trajetória; (ii) Telemetria e Comunicação, que encapsula a publicação unidirecional de dados via MQTT do robô para o backend; (iii) Gestão de Corridas, que persiste configurações de labirinto, resultados e estatísticas; e (iv) Visualização, que consome os dados persistidos para dashboards e relatórios.

\subsubsection{Visão de Processos.} O firmware embarcado executa múltiplas tarefas concorrentes sob o FreeRTOS: uma tarefa de alta prioridade para leitura de sensores e controle PID dos motores; uma tarefa de média prioridade para execução do algoritmo Flood Fill; e uma tarefa de baixa prioridade para transmissão de telemetria via Wi-Fi. O backend FastAPI opera de forma assíncrona, processando requisições HTTP e mensagens MQTT em event loops independentes, garantindo que a ingestão de telemetria não bloqueie consultas do frontend.

\subsubsection{Visão de Implementação.} O repositório está dividido em três diretórios principais: \texttt{src/firmware/} (código em C para ESP-IDF, incluindo o simulador Flood Fill em ambiente desktop); \texttt{src/backend/} (aplicação Python com FastAPI, models SQLAlchemy e migrations Alembic); e \texttt{src/frontend/} (aplicação web). Essa separação física reflete a independência das camadas e permite que diferentes subgrupos trabalhem em paralelo.

\subsubsection{Visão de Implantação.} O ESP32 funciona como cliente MQTT, conectando-se à rede local (Wi-Fi) ou a um \textit{hotspot} móvel. O backend pode ser executado localmente durante os testes de bancada ou implantado em serviços de hospedagem gratuita (ex.: Railway, Render) para acesso remoto, conforme previsto no orçamento do projeto. O frontend é servido como aplicação estática ou via servidor web integrado.

\subsubsection{Visão de Dados.} O modelo relacional é composto por três entidades principais: \texttt{Labirinto} (dimensão 4x4, 8x8 ou 16x16), \texttt{Corrida} (data, duração, velocidade média, resultado) e \texttt{EventoTelemetria} (posição X/Y, nível de bateria, timestamp). A Fig.~\ref{fig:der_micromouse} apresenta o diagrama entidade-relacionamento preliminar.

\begin{figure}[H]
    \centering
    \begin{tikzpicture}[
        entity/.style={rectangle, draw, fill=gray!10, minimum width=2.8cm, minimum height=0.9cm, font=\small\bfseries},
        relation/.style={diamond, draw, fill=gray!20, aspect=2, font=\scriptsize},
        attribute/.style={ellipse, draw, fill=gray!5, font=\scriptsize},
        arrow/.style={-Stealth, thick},
        label/.style={font=\scriptsize, midway, fill=white, inner sep=1pt}
    ]
        % Entidades
        \node[entity] (lab) at (0,0) {Labirinto};
        \node[entity] (corr) at (5,0) {Corrida};
        \node[entity] (tel) at (10,0) {EventoTelemetria};

        % Relacionamentos
        \draw[arrow] (lab) -- node[above, label] {1} node[below, label] {N} (corr);
        \draw[arrow] (corr) -- node[above, label] {1} node[below, label] {N} (tel);

        % Atributos Labirinto
        \node[attribute, below=0.6cm of lab] (dim) {dimensão};
        \draw[-] (lab) -- (dim);

        % Atributos Corrida
        \node[attribute, above=0.6cm of corr] (data) {data};
        \node[attribute, above left=0.5cm of corr] (dur) {duração};
        \node[attribute, above right=0.5cm of corr] (res) {resultado};
        \draw[-] (corr) -- (data);
        \draw[-] (corr) -- (dur);
        \draw[-] (corr) -- (res);

        % Atributos Telemetria
        \node[attribute, below=0.6cm of tel] (ts) {timestamp};
        \node[attribute, below left=0.5cm of tel] (pos) {posição X/Y};
        \node[attribute, below right=0.5cm of tel] (bat) {nível bateria};
        \draw[-] (tel) -- (ts);
        \draw[-] (tel) -- (pos);
        \draw[-] (tel) -- (bat);
    \end{tikzpicture}
    \caption{Diagrama Entidade-Relacionamento preliminar do sistema Micromouse.}
    \label{fig:der_micromouse}
\end{figure}

\subsubsection{Padrão Arquitetural.} Adotou-se o padrão em camadas (\textit{Layered Architecture}), variante cliente-servidor, por ser amplamente compreendido, de baixa complexidade para equipes acadêmicas e suficiente para os requisitos de escalabilidade do projeto. Não há necessidade de microsserviços dado o escopo reduzido e a equipe enxuta; um monolito bem modularizado atende às demandas com menor sobrecarga operacional.

\subsubsection{Alinhamento com Hardware.} A arquitetura de software foi validada em conjunto com o subgrupo de hardware. Os pinos de GPIO do ESP32 foram mapeados para os drivers de motor (DRV8833) e sensores de distância (infravermelhos), garantindo que os módulos de software de controle e leitura correspondam ao esquemático elétrico. A tabela de alocação de pinos e os valores específicos de temporização (frequência do PWM para motores, taxa de amostragem dos sensores) serão definidos em conjunto com o subgrupo de Hardware na Sprint 3 e refletidos nas configurações das tarefas do FreeRTOS.     

\subsubsection{Diagrama de Classes}

O diagrama de classes apresenta a estrutura estática do sistema Micromouse, evidenciando os principais componentes do software embarcado, do backend e da interface web, bem como os relacionamentos existentes entre eles.

No módulo embarcado, o ESP32 é responsável pela leitura dos sensores, execução do algoritmo de navegação e envio de dados de telemetria. No backend, a aplicação desenvolvida em FastAPI centraliza o processamento das informações recebidas, disponibiliza serviços para consulta e armazenamento dos dados e gerencia a comunicação com o banco de dados. A camada de persistência é composta pelas entidades de domínio que representam os labirintos, as corridas realizadas e os eventos de telemetria coletados durante a execução.

O frontend web consome os serviços disponibilizados pelo backend para exibir informações em tempo real e permitir a consulta ao histórico de execuções. Os relacionamentos entre as classes demonstram a separação de responsabilidades adotada pela arquitetura, favorecendo a manutenção, escalabilidade e reutilização dos componentes.

\begin{center}
\includegraphics[
    width=0.95\textwidth,
    height=0.8\textheight,
    keepaspectratio
]{figuras/diagrama_classe.png}

\captionof{figure}{Diagrama de Classes do Sistema Micromouse.}
\label{fig:diagrama_classe}
\end{center}

\subsubsection{Diagrama de Sequência}

O diagrama de sequência descreve o fluxo de execução de uma corrida completa do Micromouse, desde a inicialização pelo usuário até o armazenamento dos resultados no banco de dados. O objetivo é representar a interação temporal entre os componentes do sistema e evidenciar o fluxo de comunicação responsável pela transmissão e visualização dos dados de telemetria.

O processo inicia quando o operador posiciona o robô no labirinto e aciona o início da corrida. O ESP32 inicializa seus sensores e motores, inicia a execução do algoritmo de navegação e passa a coletar continuamente informações sobre posição, velocidade, tempo de execução e nível de bateria. Esses dados são enviados periodicamente ao backend através da rede sem fio.

Ao receber os dados, o backend realiza o processamento necessário, registra os eventos de telemetria e transmite as atualizações para o frontend utilizando WebSocket. Essa abordagem permite que a interface web seja atualizada em tempo real, sem a necessidade de consultas periódicas ao servidor, reduzindo a latência percebida pelo usuário.

Quando o robô atinge o objetivo do labirinto, as estatísticas finais da corrida são calculadas e enviadas ao backend, que realiza a persistência definitiva das informações no banco de dados. Em seguida, os resultados ficam disponíveis para consulta no histórico de corridas através da plataforma web.

\begin{center}
\includegraphics[
    width=0.95\textwidth,
    height=0.8\textheight,
    keepaspectratio
]{figuras/diagrama_sequencia.png}

\captionof{figure}{Diagrama de Sequência da Corrida Completa com Fluxo WebSocket.}
\label{fig:diagrama_sequencia}
\end{center}

\subsection{Roteiro de testes funcionais}

Os casos de teste presentes \autoref{apendice_roteiro_detalhado} cobrem as histórias de usuário do backlog
(HU01–HU06), incluindo todas as classificadas como \textit{Must have}, e
serão a base para a automação E2E e os testes de bancada do firmware nas
entregas seguintes. Cada caso é identificado por um código no formato
TF\textit{nn} e indica, quando aplicável, o requisito funcional (RF) e a
história de usuário (HU) rastreados.

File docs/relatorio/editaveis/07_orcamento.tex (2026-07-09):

\begin{landscape}

\chapter{Orçamento}

\begin{table}[htpb]
\begin{center}
\caption{Orçamento geral consolidado.}
\begin{tabular}{|c|c|c|}
\hline
\textbf{Geral}          & \textbf{Previsto (R\$)} & \textbf{Realizado (R\$)} \\ \hline
Matéria-prima           & 91,41                   & 90,91                    \\ \hline
Componentes eletrônicos & 228,30                  & 256,80                   \\ \hline
Componentes elétricos   & 21,65                   & 21,65                    \\ \hline
Fixadores               & 30,00                   & 0,00                     \\ \hline
Acabamento              & 52,00                   & 19,70                    \\ \hline
Montagem                & 40,00                   & 0,00                     \\ \hline
\textbf{Total}          & \textbf{463,36}         & \textbf{432,36}          \\ \hline
\end{tabular}
\end{center}
\end{table}

\clearpage

\begin{table}[htpb]
\begin{center}
\caption{Orçamento detalhado por aquisição.}
\begin{tabular}{|p{7cm}|p{3.5cm}|c|c|c|}
\hline
\textbf{Item ou serviço} & \textbf{Tipo} & \textbf{Previsto (R\$)} & \textbf{Realizado (R\$)} & \textbf{Responsável} \\ \hline
MDF para base do labirinto          & Matéria-prima & 26,00  & 0,00    & Estrutura  \\ \hline
MDF para paredes do labirinto       & Matéria-prima & 12,00  & 0,00    & Estrutura  \\ \hline
Tintas para acabamento do labirinto & Acabamento    & 52,00  & 19,70   & Estrutura  \\ \hline
Parafusos e buchas do labirinto     & Fixadores     & 12,00  & 0,00    & Estrutura  \\ \hline
Pinos cavilha do labirinto          & Fixadores     & 8,00   & 0,00    & Estrutura  \\ \hline
Filamento PLA para chassi           & Matéria-prima e Montagem & 47,50   & 45,00   & Estrutura  \\ \hline
Parafusos do chassi                 & Fixadores     & 10,00  & 0,00    & Estrutura  \\ \hline
Kit chassi robótica                 & Matéria-prima & 45,91  & 45,91   & Estrutura  \\ \hline
Microcontrolador ESP32              & Comp. eletrônico & 38,88  & 38,88  & Eletrônica \\ \hline
Chave óptica encoder (2x)           & Comp. eletrônico & 16,02  & 16,02  & Eletrônica \\ \hline
Sensor de corrente ACS712           & Comp. eletrônico & 15,29  & 15,29  & Eletrônica \\ \hline
Sensor de tensão                    & Comp. eletrônico & 12,90  & 12,90  & Eletrônica \\ \hline
Sensor IR LM393 (5x)                & Comp. eletrônico & 36,00  & 36,00  & Eletrônica \\ \hline
Mini protoboard (5x)                & Comp. eletrônico & 24,99  & 24,99  & Eletrônica \\ \hline
Ponte H DRV8833                     & Comp. eletrônico & 17,07  & 17,07  & Eletrônica \\ \hline
Módulo Step-down (2x)               & Comp. eletrônico & 21,19  & 21,19  & Eletrônica \\ \hline
Conversor ADC ADS1115               & Comp. eletrônico & 19,00  & 19,00  & Eletrônica \\ \hline
Módulo IMU MPU6050                  & Comp. eletrônico & 26,96  & 26,96  & Eletrônica \\ \hline
Sensor INA226                       & Comp. eletrônico & 28,50  & 28,50  & Eletrônica \\ \hline
Pilhas AA (12x)                      & Comp. elétrico   & 64,95  & 64,95  & Energia    \\ \hline
\textbf{Total}                      & ---           & \textbf{463,36} & \textbf{432,36} & --- \\ \hline
\end{tabular}
\end{center}
\end{table}

\begin{table}[htpb]
\begin{center}
\caption{Justificativas para itens ou serviços trocados após a aquisição.}
\begin{tabular}{|p{5cm}|p{16cm}|} \hline
\textbf{Item ou serviço} & \textbf{Justificativa}  \\ \hline
    --- &
    Até o momento, os itens adquiridos (componentes eletrônicos, pilhas e kit chassi) mantiveram os valores previstos, não havendo necessidade de substituições ou justificativas de alteração de escopo ou preço. \\ \hline
    Itens de Matéria-prima e Fixadores & Estes itens não precisaram de ser adquiridos por meio de compra pois o grupo utilizou de materiais existentes e reciclados, gerando um custo igual a R\$ 0,00. \\ \hline
    Componente Elétrico (pilhas) & As baterias precisaram ser trocadas duas vezes no decorrer do semestre, levando a equipe a comprar mais dois pacotes com 4 pilhas \\ \hline
\end{tabular}
\end{center}
\end{table}

\end{landscape}

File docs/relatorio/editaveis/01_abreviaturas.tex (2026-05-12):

\begin{siglas}
  \item[ADC] Conversor Analógico-Digital (\textit{Analog-to-Digital Converter})
  \item[API] Interface de Programação de Aplicações (\textit{Application Programming Interface})
  \item[BPMN] Modelo e Notação de Processos de Negócio (\textit{Business Process Model and Notation})
  \item[CAD] Desenho Assistido por Computador (\textit{Computer-Aided Design})
  \item[EAP] Estrutura Analítica do Projeto
  \item[ESP-IDF] \textit{Espressif IoT Development Framework}
  \item[FCTE] Faculdade de Ciências e Tecnologias em Engenharia
  \item[FGA] Faculdade UnB Gama
  \item[HTTP] Protocolo de Transferência de Hipertexto (\textit{Hypertext Transfer Protocol})
  \item[HU] História de Usuário
  \item[IR] Infravermelho (\textit{Infrared})
  \item[KPI] Indicador-Chave de Desempenho (\textit{Key Performance Indicator})
  \item[MDF] Placa de Fibra de Média Densidade (\textit{Medium Density Fiberboard}) 
  \item[MQTT] \textit{Message Queuing Telemetry Transport}
  \item[NiMH] Níquel-Metal Hidreto
  \item[PI1] Projeto Integrador de Engenharia 1
  \item[PLA] Ácido Polilático (\textit{Polylactic Acid})
  \item[PWM] Modulação por Largura de Pulso (\textit{Pulse Width Modulation})
  \item[REST] Transferência de Estado Representacional (\textit{Representational State Transfer})
  \item[RF] Requisito Funcional
  \item[RNF] Requisito Não Funcional
  \item[STEM] Ciência, Tecnologia, Engenharia e Matemática (\textit{Science, Technology, Engineering, and Mathematics})
  \item[TF] Teste Funcional
  \item[UC] Caso de Uso (\textit{Use Case})
  \item[UML] Linguagem de Modelagem Unificada (\textit{Unified Modeling Language})
  \item[UnB] Universidade de Brasília
\end{siglas}

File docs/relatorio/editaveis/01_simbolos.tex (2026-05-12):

\begin{simbolos}
  \item[$A$] Ampère (Corrente Elétrica)
  \item[$cm$] Centímetro
  \item[$dBm$] Decibel-miliwatt 
  \item[$E$] Energia 
  \item[$Hz$] Hertz
  \item[$I$] Corrente elétrica
  \item[$I^2C$] \textit{Inter-Integrated Circuit}
  \item[$J$] Joule
  \item[$mA$] Miliampère
  \item[$mAh$] Miliampère-hora
  \item[$mm$] Milímetro
  \item[$s$] Segundo
  \item[$V$] Volt (Tensão Elétrica)
  \item[$Wh$] Watt-hora
  \item[$\Delta t$] Variação de tempo
\end{simbolos}

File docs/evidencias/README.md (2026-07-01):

# Evidências — Integração E2E do lado software (4x4)

Validação **do lado software** da cadeia telemetria → persistência → histórico,
relacionada às issues **#22** (integração E2E no 4x4) e **#27** (critérios de
aceitação). Não substitui a validação com o robô físico — cobre tudo o que é
verificável sem hardware.

## Como foi feito

Um navegador real (Chromium, via Playwright) carrega o frontend e conecta no
WebSocket do backend. Um script simula o ESP32 enviando telemetria por `POST
/telemetria` (abre a corrida, anda do canto `(0,0)` até o centro `(1,1)` do 4x4)
e depois encerra a corrida por `POST /corridas/{id}/encerrar`.

- Backend: FastAPI (`uvicorn`) em `:8000`, SQLite migrado + `seed.py`.
- Frontend: Vite em `:5173`.

## Resultado — PASS ✅

| Verificação | Esperado | Resultado |
|---|---|---|
| Conexão WebSocket | indicador "Conectado" | ✅ |
| Telemetria ao vivo | trajeto e posição no mapa; painel atualizando | ✅ |
| Bateria | 85% | ✅ |
| Desafio cumprido (chegou ao centro) | Sim | ✅ |
| Posição atual | (1, 1) | ✅ |
| Velocidade média | 0.42 m/s | ✅ |
| Encerramento (#16) | HTTP 200, `duracao=6s`, `resultado=concluida` | ✅ |
| Persistência + histórico | corrida aparece como "4x4 · 00:00:06 · Concluída" | ✅ |

## Arquivos

- `01_conectado.png` — tela conectada ao WebSocket.
- `02_telemetria_ao_vivo.png` — telemetria ao vivo (mapa + painel de métricas).
- `03_historico.png` — histórico refletindo a corrida finalizada.
- `log.txt` — saída do script com os `CHECK ... PASS`.

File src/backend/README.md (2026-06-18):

# Backend

Backend da aplicação desenvolvido com FastAPI.

---
## 📖 Descrição do Projeto
Backend responsável por receber, processar e disponibilizar dados de telemetria do sistema Micromouse.

---

## 📁 Estrutura do Projeto

```bash
backend/
├── app/
│   ├── routes/
│   │   ├── health.py
│   │   └── telemetria.py
│   ├── models/
│   ├── schemas/
│   └── main.py
├── tests/
│   ├── conftest.py
│   ├── test_health.py
│   └── test_telemetria.py
├── pytest.ini
├── requirements.txt
└── README.md
```

---

## 🚀 Como rodar localmente

### 1. Clonar o repositório

```bash
git clone https://github.com/fcte-pi1/2026_1_PI1_Grupo01_Juliana.git
```

---

### 2. Entrar na pasta do projeto

```bash
cd src/backend
```

---

### 3. Criar e ativar ambiente virtual

#### Linux/macOS

```bash
python -m venv venv
source venv/bin/activate
```

#### Windows

```bash
python -m venv venv
venv\Scripts\activate
```

---

### 4. Instalar as dependências

```bash
pip install -r requirements.txt
```

> Requer **Python 3.10+** (o `requirements.txt` fixa `alembic 1.18.4`,
> que não suporta versões anteriores).

---

### 5. Aplicar as migrations

```bash
PYTHONPATH=. alembic upgrade head
```

> O `PYTHONPATH=.` é necessário porque `migrations/env.py` importa
> `from app.database import Base`. Sem ele o alembic falha com
> `ModuleNotFoundError: No module named 'app'`. Alternativa equivalente:
> `python -m alembic upgrade head`.

(Opcional) Popular o banco com dados de exemplo:

```bash
PYTHONPATH=. python seed.py
```

---

### 6. Executar o servidor

```bash
uvicorn app.main:app --reload
```

A aplicação ficará disponível em:

```bash
http://localhost:8000
```

---

## 🌐 Configuração de rede (acesso por outra máquina)

Por padrão o backend só aceita requisições do frontend local
(`http://localhost:5173`). Para que o ESP32 ou outro computador na mesma rede
acessem a API, há dois ajustes:

**1. Liberar a origem do frontend no CORS.** As origens são lidas da variável
de ambiente `CORS_ORIGINS` (lista separada por vírgula). Copie o exemplo e
ajuste:

```bash
cp .env.example .env
# edite .env e inclua o endereço do frontend pela rede, ex.:
# CORS_ORIGINS=http://localhost:5173,http://192.168.0.10:5173
```

O `.env` é carregado automaticamente na inicialização (via `python-dotenv`) e
**não** é versionado. Sem ele, vale o default local.

**2. Expor o servidor na rede.** O `uvicorn` sobe em `127.0.0.1` por padrão
(inacessível de fora). Use `--host 0.0.0.0` para escutar em todas as interfaces:

```bash
uvicorn app.main:app --reload --host 0.0.0.0
```

Descubra o IP da máquina (ex.: `ipconfig getifaddr en0` no macOS,
`hostname -I` no Linux) e acesse de outro dispositivo por
`http://<IP-da-máquina>:8000`.

---

## ✅ Testes automatizados (pytest + cobertura)

> 🤖 **Precisa do robô / ESP32 / sensores para rodar os testes? NÃO.**
> Os testes automatizados rodam **100% sem hardware** e sem internet. Você só
> precisa de **Python + as dependências do `requirements.txt`**. Não é preciso
> ter o ESP32, o robô montado, sensores calibrados, Wi-Fi ou MQTT.
>
> Por quê:
> - O banco usado é um **SQLite em memória**, criado e destruído a cada teste
>   (não toca no `micromouse.db` nem em banco nenhum de verdade).
> - Os pacotes de telemetria são **fabricados dentro do próprio teste** (fixture
>   `pacote_telemetria`), simulando exatamente o que o robô enviaria — então não
>   há robô de verdade enviando dados.
> - O servidor sobe em memória pelo `TestClient`; **não** é preciso rodar o
>   `uvicorn` à parte.
>
> O hardware (ESP enviando telemetria real) só importa para a **integração de
> sistema** / demonstração do robô — que é outra entrega, não estes testes.

A suíte de testes fica em `tests/` e roda sobre um **banco SQLite isolado em
memória** — não toca no `micromouse.db`. A configuração está no `pytest.ini`
(cobertura via `pytest-cov` já habilitada).

```bash
# com o venv ativado e dentro de src/backend
pip install -r requirements.txt   # garante pytest e pytest-cov
pytest                            # roda tudo + relatório de cobertura no terminal
```

O relatório HTML detalhado é gerado em `htmlcov/index.html`. Para rodar um
arquivo ou teste específico:

```bash
pytest tests/test_telemetria.py
pytest tests/test_telemetria.py::test_post_telemetria_labirinto_inexistente_retorna_404
```

### Fixtures disponíveis (em `tests/conftest.py`)

Use-as nos novos testes — basta declará-las como argumento da função:

| Fixture | Para que serve |
| --- | --- |
| `client` | `TestClient` da API já conectado ao banco de teste. |
| `db_session` | Sessão SQLAlchemy para montar dados direto no banco. |
| `labirintos` | Semeia os 3 labirintos e retorna `{"4x4": id, "8x8": id, "16x16": id}`. |
| `pacote_telemetria` | Construtor de payload de telemetria válido (aceita `**overrides`). |

Exemplo (ver `tests/test_telemetria.py`):

```python
def test_exemplo(client, labirintos, pacote_telemetria):
    resp = client.post("/telemetria", json=pacote_telemetria(labirinto_id=labirintos["4x4"]))
    assert resp.status_code == 201
```

> A meta da entrega é **cobertura ≥ 70%**. Os testes-modelo já cobrem health e
> os casos básicos do `POST /telemetria`; as suítes completas (WebSocket,
> models/schemas, histórico) são as Tarefas T6–T9.

---

## 🧪 Como testar a API

### POST `/telemetria` pelo Swagger

O FastAPI já gera uma documentação interativa em
<http://localhost:8000/docs>.

1. Abra <http://localhost:8000/docs>.
2. Clique no endpoint `POST /telemetria`.
3. Clique em **Try it out**.
4. Cole o JSON abaixo no campo de body e clique em **Execute**:

   ```json
   {
     "corrida_id": 1,
     "timestamp": "2026-05-10T12:34:56Z",
     "posicao_x": 2,
     "posicao_y": 3,
     "nivel_bateria": 87.5,
     "velocidade": 0.42
   }
   ```

5. A resposta (status `201` + body com o evento criado) aparece logo
   abaixo.

### WebSocket `/ws/telemetria` pelo Postman

O Swagger não suporta WebSocket — use o Postman:

1. No Postman, clique em **New → WebSocket Request**.
2. Cole a URL: `ws://localhost:8000/ws/telemetria`.
3. Clique em **Connect**.
4. Na aba **Message**, selecione **JSON** e envie:

   ```json
   {
     "corrida_id": 1,
     "timestamp": "2026-05-10T12:36:00Z",
     "posicao_x": 5,
     "posicao_y": 5,
     "nivel_bateria": 70.0,
     "velocidade": 0.55
   }
   ```

5. O backend responde com o evento persistido (mesmo JSON com `id`
   gerado). Para ver o broadcast, abra **duas conexões** Postman para a
   mesma URL — ao enviar pacote em uma, ambas recebem.

---

## ✅ Endpoint de Health Check

Endpoint responsável por verificar se a API está online.

### Requisição

```http
GET /health
```

### Resposta esperada

```json
{
  "status": "OK"
}
```

---

## 📡 Telemetria

Recebimento dos pacotes enviados pelo micromouse durante uma corrida.
Há duas formas equivalentes: `POST /telemetria` para envios pontuais e
`WebSocket /ws/telemetria` para fluxo contínuo em tempo real (com
broadcast para todos os clientes conectados).

### Payload

```json
{
  "corrida_id": 1,
  "labirinto_id": 2,
  "timestamp": "2026-05-10T12:34:56Z",
  "posicao_x": 2,
  "posicao_y": 3,
  "nivel_bateria": 87.5,
  "velocidade": 0.42
}
```

| Campo | Tipo | Obrigatório | Observação |
| --- | --- | --- | --- |
| `corrida_id` | int | condicional | Usa uma corrida já existente. |
| `labirinto_id`  | int | condicional | Se `corrida_id` não for enviado, abre uma nova corrida. |
| `timestamp` | ISO8601 | sim | Momento da leitura. |
| `posicao_x` | int ≥0  | sim | Coordenada na grade. |
| `posicao_y` | int ≥0  | sim | Coordenada na grade. |
| `nivel_bateria` | float | sim | Porcentagem 0–100. |
| `velocidade` | float | não | m/s. |

> Pelo menos um entre `corrida_id` e `labirinto_id` deve ser informado.

### POST `/telemetria`

Recebe um pacote pontual de telemetria. Resposta `201`:

```json
{
  "id": 4,
  "corrida_id": 1,
  "timestamp": "2026-05-10T12:34:56",
  "posicao_x": 2,
  "posicao_y": 3,
  "nivel_bateria": 87.5,
  "velocidade": 0.42
}
```

> Veja a seção [🧪 Como testar a API](#-como-testar-a-api) para o
> passo-a-passo no Swagger.

### WebSocket `/ws/telemetria`

- O cliente envia mensagens JSON com o mesmo payload do POST.
- Cada pacote válido é persistido e re-emitido para todos os clientes
  conectados (inclusive o produtor), permitindo dashboards em tempo real.
- Pacotes inválidos retornam `{"erro": "...", "detalhes": [...]}` apenas
  para o emissor.

> Veja a seção [🧪 Como testar a API](#-como-testar-a-api) para o
> passo-a-passo no Postman.

---

## 📦 Dependências

As dependências estão definidas no arquivo:

```bash
requirements.txt
```

### Principais bibliotecas utilizadas

- FastAPI
- Uvicorn
- Pydantic
- Python Dotenv
- HTTPX

---

## 🛠️ Tecnologias Utilizadas

- Python 3.x
- FastAPI
- Uvicorn
- Pydantic

---

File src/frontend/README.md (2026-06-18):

# React + Vite

This template provides a minimal setup to get React working in Vite with HMR and some ESLint rules.

Currently, two official plugins are available:

- [@vitejs/plugin-react](https://github.com/vitejs/vite-plugin-react/blob/main/packages/plugin-react) uses [Oxc](https://oxc.rs)
- [@vitejs/plugin-react-swc](https://github.com/vitejs/vite-plugin-react/blob/main/packages/plugin-react-swc) uses [SWC](https://swc.rs/)

## React Compiler

The React Compiler is not enabled on this template because of its impact on dev & build performances. To add it, see [this documentation](https://react.dev/learn/react-compiler/installation).

## Expanding the ESLint configuration

If you are developing a production application, we recommend using TypeScript with type-aware lint rules enabled. Check out the [TS template](https://github.com/vitejs/vite/tree/main/packages/create-vite/template-react-ts) for information on how to integrate TypeScript and [`typescript-eslint`](https://typescript-eslint.io) in your project.

## 🌐 Configuração de rede (backend por IP)

As URLs do backend (API REST e WebSocket de telemetria) são configuráveis por
variável de ambiente. Sem configuração, o frontend assume o backend **no mesmo
host** em que a página foi aberta, na porta `8000` — ou seja, o acesso pela rede
já funciona automaticamente ao abrir o site por `http://<IP-da-máquina>:5173`.

Para fixar um backend específico, copie o exemplo e ajuste:

```bash
cp .env.example .env
# edite .env, ex.:
# VITE_API_URL=http://192.168.0.10:8000
# VITE_WS_URL=ws://192.168.0.10:8000/ws/telemetria
```

O Vite só expõe variáveis com prefixo `VITE_`. O `.env` real **não** é
versionado. Para servir a aplicação na rede (acessível de outro dispositivo),
rode o Vite com `--host`:

```bash
npm run dev -- --host
```

> Lembre-se de liberar a origem do frontend no `CORS_ORIGINS` do backend
> (veja o README do backend).

## ✅ Testes automatizados (Vitest + Testing Library)

> 🤖 **Precisa do robô / ESP32 / backend rodando para os testes? NÃO.**
> Os testes do frontend rodam **100% sem hardware e sem backend**. Eles usam o
> **jsdom** (um DOM em memória, sem navegador) e, quando uma página precisar de
> dados da API ou de WebSocket, isso é **mockado** dentro do próprio teste. Você
> só precisa do **Node + as dependências do `package.json`**.

### Como rodar

```bash
# dentro de src/frontend
npm install            # instala as dependências (inclui Vitest e Testing Library)
npm test               # roda todos os testes uma vez
npm run test:watch     # modo interativo (re-roda ao salvar)
npm run test:coverage  # roda com relatório de cobertura
```

O relatório HTML de cobertura é gerado em `coverage/index.html`. A meta da
entrega é **cobertura ≥ 70%**.

### Onde ficam os testes

- Os testes ficam **ao lado do arquivo testado**, com sufixo `.test.jsx`
  (ex.: `src/App.test.jsx`, futuramente `src/pages/History.test.jsx`).
- O setup global está em `src/test/setup.js` (matchers do jest-dom + limpeza do
  DOM entre testes). `describe/it/expect` são **globais** — não precisa importar.

### Padrão para novos testes

Use `render` + `screen` do Testing Library e consulte por papel/texto (como o
usuário enxerga). Veja o molde em `src/App.test.jsx`:

```jsx
import { render, screen } from '@testing-library/react'
import History from './pages/History'

it('exemplo', () => {
  render(<History />)
  expect(screen.getByText('Histórico de Corridas')).toBeInTheDocument()
})
```

> O smoke test atual cobre o `App` (navegação + página inicial). As suítes
> completas das páginas e componentes são as Tarefas T10–T12.

## 🎭 Testes E2E / sistema (Playwright)

Diferente dos testes acima (que rodam em `jsdom`), os testes **E2E** abrem a
aplicação em um **navegador real** (Chromium headless) e validam os fluxos do
ponto de vista do usuário — são os testes de sistema/funcional exigidos na
seção 7.5 do relatório.

### Como rodar

```bash
# dentro de src/frontend
npm install                  # instala dependências (inclui @playwright/test)
npx playwright install chromium   # baixa o navegador (só na primeira vez)
npm run e2e                  # roda os testes E2E (headless)
npm run e2e:ui               # modo interativo (UI do Playwright)
npm run e2e:report           # abre o último relatório HTML
```

Não precisa subir o frontend manualmente: o `playwright.config.js` tem um
`webServer` que executa `npm run dev` automaticamente antes dos testes.

### Onde ficam os testes

- Os specs E2E ficam em **`e2e/`** com sufixo `.spec.js` (ex.: `e2e/smoke.spec.js`).
  Eles **não** são executados pelo Vitest (o Vitest está restrito a `src/`).
- Configuração em `playwright.config.js`.

### ⚠️ E2E que dependem do backend (Tarefas T13–T15)

O `webServer` padrão sobe **apenas o frontend** — suficiente para o smoke test e
fluxos de navegação. Os E2E que precisam de **dados reais da API** (telemetria,
histórico) devem subir também o backend. Para isso, transforme o `webServer` em
uma lista no `playwright.config.js`:

```js
webServer: [
  { command: 'npm run dev', url: 'http://localhost:5173', reuseExistingServer: !process.env.CI },
  {
    // backend: ajuste o caminho do uvicorn ao seu ambiente (venv)
    command: 'cd ../backend && venv/bin/python -m uvicorn app.main:app --port 8000',
    url: 'http://localhost:8000/health',
    reuseExistingServer: !process.env.CI,
  },
],
```

> Os fluxos E2E devem seguir o **roteiro de testes funcionais** (Tarefa T2).
> O molde inicial está em `e2e/smoke.spec.js`.

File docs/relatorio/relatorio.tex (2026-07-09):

\documentclass[12pt,openright,oneside,a4paper,english,french,spanish,brazil,nohyperref]{abntex2}
\input{fixos/pacotes}
\input{fixos/comandos}
\usepackage{fixos/customizacoes}
\usepackage{placeins}

\input{editaveis/00_informacoes}
\input{fixos/informacoes}
\input{fixos/setup}

\begin{document}

\frenchspacing
\imprimircapa
\imprimirfolhaderosto* {}

\input{fixos/fichaCatalografica}

\input{editaveis/02_resumo}
\input{fixos/listasAutomaticas}
\input{editaveis/01_abreviaturas}
\input{editaveis/01_simbolos}
\input{fixos/indiceAutomatico}

\textual

\input{editaveis/03_introducao}
\input{editaveis/04_termodeaberturadoprojeto}
\input{editaveis/05_equipe}
\input{editaveis/06_projetoconceitual}
\input{editaveis/07_orcamento}
\input{editaveis/08_cronograma}
\input{editaveis/09_resultados}
\input{editaveis/10_licoes}

\bookmarksetup{startatroot}

\postextual

\bibliography{bibliografia}
\input{editaveis/11_apendices}
% \input{editaveis/12_anexos}
\printindex

\end{document}

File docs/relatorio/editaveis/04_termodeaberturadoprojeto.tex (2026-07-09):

\chapter{Termo de Abertura do Projeto}

\section{Dados do projeto}
\begin{description}
    \item [Nome do Projeto:] Micromouse - PI1
    \item [Data de abertura:] 16/03/2026
    \item [Código:] FGA0303 (Grupo 1 - Juliana)
    \item [Patrocinador:] Universidade de Brasília
    \item [Gerente:] André Cláudio Maia da Cunha
        \begin{description}
            \item [Matrícula:] 222037648
            \item [E-mail:] 222037648@aluno.unb.br
            \item [Telefone:] (61) 99663-7828
        \end{description}
\end{description}

\section{Objetivos}

O projeto tem como principal objetivo desenvolver e construir um robô autônomo com chassi em impressão 3D, capaz de resolver labirintos desconhecidos de dimensões 4x4 e 8x8 células. O sistema integrará componentes mecânicos, de hardware embarcado
e algoritmos de exploração, como o Flood Fill, para detectar paredes, realizar mapeamento incremental e alcançar o centro do trajeto no menor tempo possível sem qualquer tipo de intervenção humana. Além do robô, o projeto engloba a construção de um labirinto
modular de MDF padronizado para testes e um sistema web de telemetria para visualização de dados de navegação e energia em tempo real.

Para avaliar a eficácia do projeto e atestar a integração multidisciplinar técnica do produto desenvolvido, foram estabelecidos os seguintes indicadores-chave de desempenho (KPIs), os quais irão nortear as entregas acadêmicas do projeto:

\begin{enumerate}
    \item \textbf{Autonomia e Resolução:} Capacidade do robô de alcançar o objetivo central dos labirintos sem intervenções humanas, mapeando incrementalmente as células usando seus módulos sensoriais.
    \item \textbf{Eficiência do Algoritmo de Navegação:} Tempo e quantidade de tentativas necessárias para a resolução da rota, atestando o funcionamento de lógica embarcada.
    \item \textbf{Precisão da Telemetria:} Confiabilidade da comunicação sem fio do ESP32, garantindo o envio, processamento e visualização em tempo real de informações como posição, tempo, velocidade média e bateria com baixa latência. 
    \item \textbf{Resistência, Escalabilidade e Peso:} Integridade do chassi e obediência à restrição de tamanho máximo de 25 cm x 25 cm para largura e comprimento, de modo a assegurar que não haja danos no contato com as paredes. 
    \item \textbf{Autonomia Energética:} Duração operacional contínua mínima de 30 minutos em pista, validando o circuito \textit{step-down} construído e o correto dimensionamento das baterias de NiMH mediante margem de segurança contra picos de corrente.
\end{enumerate}

\section{Mercado-alvo}

O mercado-alvo deste projeto abrange a comunidade acadêmica e entusiastas das engenharias e robótica competitiva. Trata-se de um sistema direcionado inicialmente a estudantes, professores, pesquisadores das áreas de eletrônica, software, energia, estruturas e participantes de feiras tecnológicas e eventos como competições micromouse.
Além disso, o projeto possui potencial expressivo de uso como plataforma didática para o ensino em disciplinas de engenharia integrando hardware, software, sensoriamento e controle dinâmico de estruturas físicas.

\section{Requisitos}

Os requisitos do sistema foram analisados, revisados e divididos em categorias funcionais e não funcionais. A priorização adotada reflete o nível de criticidade de cada item para o funcinamento do Micromouse, garantindo o alinhamento com o escopo e as regras da competição simulada.

\begin{landscape}
    \setlength{\LTleft}{0pt}
    \setlength{\LTright}{0pt}

    \begin{longtable}{@{\extracolsep{\fill}}|l|p{14.5cm}|l|l|}
        
        \caption{Requisitos Funcionais e Não Funcionais} \label{tab:requisitos} \\
        
        \hline
        \textbf{ID} & \textbf{Requisito} & \textbf{Categoria} & \textbf{Prioridade} \\ \hline
        \endfirsthead

        \hline
        \textbf{ID} & \textbf{Requisito} & \textbf{Categoria} & \textbf{Prioridade} \\ \hline
        \endhead

        \hline
        \endfoot

        \hline
        \endlastfoot

        \multicolumn{4}{|c|}{\textbf{REQUISITOS FUNCIONAIS (RF)}} \\ \hline
        RF01 & O sistema deve navegar de forma autônoma em labirintos 4x4, 8x8 e 16x16 após a ativação. & Navegação & Must have \\ \hline
        RF02 & O sistema deve detectar paredes e mapear o ambiente progressivamente em tempo real. & Navegação & Must have \\ \hline
        RF03 & O sistema deve decidir a rota utilizando algoritmos de resolução de labirintos (ex: Flood Fill). & Navegação & Must have \\ \hline
        RF04 & O sistema deve identificar o momento em que o robô atinge o centro do labirinto. & Navegação & Must have \\ \hline
        RF05 & O sistema deve calcular e percorrer a rota mais rápida de retorno à origem após o mapeamento. & Navegação & Could have \\ \hline
        RF06 & O sistema deve processar dados dos sensores de distância continuamente para detectar obstáculos e paredes. & Sensoriamento & Must have \\ \hline
        RF07 & O sistema deve monitorar sua posição continuamente via odometria e controle de orientação. & Sensoriamento & Must have \\ \hline
        RF08 & O sistema deve aferir o nível de bateria via leitura analógica com divisor de tensão. & Sensoriamento & Must have \\ \hline
        RF09 & O sistema deve transmitir dados de telemetria sem fio para o servidor. & Transmissão de Dados & Must have \\ \hline
        RF10 & O sistema web deve exibir telemetria em tempo real (tipo de labirinto, velocidade, trajeto, tempo e bateria). & Visualização & Must have \\ \hline
        RF11 & O sistema web deve exibir um indicador de status atestando o cumprimento da missão. & Visualização & Must have \\ \hline
        RF12 & O sistema deve armazenar dados de corridas concluídas de forma persistente em banco de dados. & Armazenamento & Must have \\ \hline
        RF13 & O sistema web deve permitir consulta ao histórico e comparação de desempenho entre execuções. & Visualização & Should have \\ \hline
        RF14 & O sistema deve identificar as dimensões do labirinto automaticamente ou via seletor físico antes da ativação. & Navegação & Must have \\ \hline
        RF15 & O sistema web deve permitir filtrar o histórico de dados por dimensões do labirinto ou exibir todos. & Visualização & Should have \\ \hline

        % --- REQUISITOS NÃO FUNCIONAIS ---
        \multicolumn{4}{|c|}{\textbf{REQUISITOS NÃO FUNCIONAIS (RNF)}} \\ \hline
        RNF01 & O robô deve possuir no máximo 25 cm de comprimento e de largura. & Restrição Física & Must have \\ \hline
        RNF02 & O robô não deve usar motores de combustão, voar, pular ou danificar o labirinto. & Restrição Física & Must have \\ \hline
        RNF03 & O banco de baterias deve representar no máximo 25\% do peso total do robô. & Restrição Física & Should have \\ \hline
        RNF04 & O processamento do sistema embarcado deve utilizar exclusivamente o microcontrolador ESP32. & Tecnologia & Must have \\ \hline
        RNF05 & O sistema de alimentação deve prover autonomia mínima de 30 minutos contínuos. & Energia & Must have \\ \hline
        RNF06 & O sistema deve computar e decidir a rota na célula atual em até 5 segundos. & Desempenho & Must have \\ \hline
        RNF07 & A interface web deve exibir telemetria com latência máxima de 500 ms. & Desempenho & Must have \\ \hline
        RNF08 & Em parada de emergência, os atuadores devem cessar movimento em no máximo 2 segundos. & Confiabilidade e Segurança & Must have \\ \hline
        RNF09 & O código-fonte e o mapa não devem sofrer modificações remotas durante a execução na pista. & Segurança e Confiabilidade & Must have \\ \hline
        RNF10 & O banco de dados para armazenamento de corridas deve possuir arquitetura relacional. & Tecnologia & Should have \\ \hline

    \end{longtable}
\end{landscape}

\section{Justificativa}

O desenvolvimento do Micromouse configura-se como um campo de testes real e prático das disciplinas da Faculdade de Ciências e Tecnologias em Engenharia (FCTE), exigindo um corpo de estudantes não apenas o conhecimento teórico, mas habilidades de execução. Assim, a justificativa deste projeto
se fundamenta na necessidade inerente de preparar futuros profissionais em sistemas interligados de áreas multidisciplinares de hardware, software e estrutural aplicados ao mundo real.

\section{Indicadores}

A listagem a seguir explicita até dez indicadores numéricos que evidenciam o impacto mercadológico e aplicabilidade prática do sistema como objeto técnico de robótica educacional e competitiva:

\begin{enumerate}
    \item Percentual de precisão na detecção e mapeamento de paredes do labirinto.
    \item Número estimado de laboratórios no DF que poderiam usar o modelo para ensino de eletrônica e programação.
    \item Tempo médio (em milissegundos) de comunicação entre o sistema web de telemetria e o microcontrolador ESP32 na pista.
    \item Custo total do chassi 3D (PLA) e módulos embarcados comparado a kits proprietários tradicionais do mercado.
    \item Autonomia média suportada pelo banco de baterias dimensionado frente às atividades dos motores e placas.
    \item Quantidade de commits e issues de projetos gerados no Github atestando o engajamento dos alunos nas Sprints propostas.
    \item Índices de sucesso da navegação autônoma em pistas progressivamente mais complexas (4x4 vs 8x8).
\end{enumerate}

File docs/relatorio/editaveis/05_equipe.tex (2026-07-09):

\begin{landscape}

\chapter{Equipe de Trabalho}

\begin{table}[htpb]
\begin{center}
\caption{Composição da equipe.}
\begin{tabular}{|c|c|c|c|c|c|}
\hline
\textbf{Nome} & \textbf{Matrícula} & \textbf{Curso} & \textbf{Telefone} & \textbf{E-mail} & \textbf{Atribuições}\\ \hline
André Cláudio Maia da Cunha           & 222037648        & Eng. de Software     & (61) 99663-7828   & 222037648@aluno.unb.br & \textbf{Gerência}, energia\\ \hline
Arthur Porto Monteiro Mühlhofer       & 232024518        & Eng. Aeroespacial    & (61) 99859-0402   & 232024518@aluno.unb.br & \textbf{Subgerência}, estrutura \\ \hline
Davi de Aguiar Vieira                 & 222006641        & Eng. de Software     & (61) 98354-9406   & 222006641@aluno.unb.br & Energia \\ \hline
Enrico Martins Mantoan Zoratto        & 222006688        & Eng. de Software     & (61) 99651-7788   & 222006688@aluno.unb.br & Hardware \\ \hline
Filipe Bressanelli Azevedo Filho      & 222024579        & Eng. de Software     & (61) 99978-0505   & 222024579@aluno.unb.br & Energia \\ \hline
Guilherme Brito de Souza              & 190028963        & Eng. de Software     & (61) 99268-7701   & 190028963@aluno.unb.br & Software \\ \hline
Gustavo Henrique Rodrigues de Sousa   & 211030783        & Eng. de Software     & (61) 99677-1434   & 211030783@aluno.unb.br & Software \\ \hline
Ian Lima da Costa                     & 211039493        & Eng. Eletrônica      & (61) 99669-0593   & 211039493@aluno.unb.br & \textbf{Subgerência}, hardware \\ \hline
Manoela Silvestre Garcia Chaves       & 222015186        & Eng. de Software     & (61) 98119-9559   & 222015186@aluno.unb.br & Software \\ \hline
Manuella Magalhães Valadares          & 222021890        & Eng. de Software     & (61) 99430-0737   & 222021890@aluno.unb.br & Estrutura \\ \hline
Marcos Vieira Marinho                 & 222021906        & Eng. de Software     & (61) 98518-0288   & 222021906@aluno.unb.br & Estrutura  \\ \hline
Mateus de Castro Santos               & 222015195        & Eng. de Software     & (61) 99842-3397   & 222015195@aluno.unb.br & Estrutura  \\ \hline
Melissa de Sousa Santos               & 211062295        & Eng. de Energia      & (61) 99318-4699   & 211062295@aluno.unb.br & \textbf{Subgerência}, energia \\ \hline
Noboru Watanabe                       & 231026527        & Eng. Eletrônica      & (61) 99862-0200   & 231026527@aluno.unb.br & hardware \\ \hline 
Otávio Lopes                          & 231038232        & Eng. Aeroespacial    & (61) 98420-1491   & 231038232@aluno.unb.br & estrutura \\ \hline 
Pedro Lucas Dourado Santos            & 211039680        & Eng. de Software     & (63) 98426-7474   & 211039680@aluno.unb.br & hardware \\ \hline 
Pedro Lopes da Cunha                  & 211039671        & Eng. de Software     & (61) 99939-5131   & 211039671@aluno.unb.br & hardware \\ \hline 
Thales Henrique Euflauzino dos Santos & 222006178        & Eng. de Software     & (61) 99503-3133   & 222006178@aluno.unb.br & \textbf{Subgerência}, software \\ \hline 
Victor Hugo dos Santos Bernardes      & 222029243        & Eng. de Software     & (61) 99268-7756   & 222029243@aluno.unb.br & software \\ \hline 
\end{tabular}
\end{center}
\end{table}

\clearpage

\begin{table}[htpb]
\begin{center}
\caption{Avaliação de desempenho da equipe}
\begin{tabular}{|c|c|c|c|c|c|c|c|}
\hline
 & \textbf{Avaliação} & \textbf{Moti-} & \textbf{Comprome-} & \textbf{Conhecimento} & \textbf{Cumpriu} & \textbf{Comuni-} & \textbf{Gestão} \\
 \textbf{Nome} & \textbf{geral} & \textbf{vação} & \textbf{timento} & \textbf{técnico} & \textbf{prazos} & \textbf{cação} & \textbf{de conflitos} \\ \hline
André Cláudio Maia da Cunha & +++++ & +++ & +++++ & +++ & +++++ & +++++ & + \\ \hline
Arthur Porto Monteiro Mühlhofer & +++++ & +++ & +++ & +++++ & +++ & + & +++ \\ \hline
Davi de Aguiar Vieira & +++++ & +++ & +++++ & + & +++++ & +++ & +++++ \\ \hline
Enrico Martins Mantoan Zoratto & +++++ & +++++ & +++ & +++ & +++ & +++ & +++ \\ \hline
Filipe Bressanelli Azevedo Filho & +++++ & +++ & +++++ & + & +++++ & +++++ & +++++ \\ \hline
Guilherme Brito de Souza & +++++ & +++++ & +++++ & +++++ & +++++ & + & +++ \\ \hline
Gustavo Henrique Rodrigues de Sousa & +++++ & +++++ & +++++ & +++++ & +++++ & +++++ & +++++ \\ \hline
Ian Lima da Costa & +++++ & +++++ & +++ & +++ & +++ & +++ & +++ \\ \hline
Manoela Silvestre Garcia Chaves & +++++ & +++++ & +++++ & +++++ & +++++ & +++++ & +++++ \\ \hline
Manuella Magalhães Valadares & +++++ & +++++ & +++++ & +++++ & +++++ & +++++ & +++++ \\ \hline
Marcos Vieira Marinho & +++++ & +++++ & +++++ & +++ & +++++ & +++++ & +++++ \\ \hline
Mateus de Castro Santos & +++++ & +++++ & +++++ & + & +++++ & +++++ & +++++ \\ \hline
Melissa de Sousa Santos & +++++ & +++ & +++++ & +++++ & +++++ & +++ & +++++ \\ \hline
Noboru Watanabe & +++++ & +++++ & +++++ & +++++ & +++++ & +++++ & +++++ \\ \hline
Otávio Lopes & +++++ & +++++ & +++++ & +++++ & +++++ & +++ & +++ \\ \hline
Pedro Lucas Dourado Santos & +++++ & +++ & +++++ & +++ & +++++ & +++++ & +++++ \\ \hline
Pedro Lopes da Cunha & +++++ & +++ & +++ & +++ & +++++ & +++ & +++ \\ \hline
Thales Henrique Euflauzino dos Santos & +++++ & +++++ & +++++ & +++++ & +++++ & +++++ & +++++ \\ \hline
Victor Hugo dos Santos Bernardes & +++++ & +++++ & +++++ & +++++ & +++++ & +++++ & +++++ \\ \hline
\multicolumn{8}{c}{\textit{Legenda}: +++++: \textit{atende às expectativas}; +++: \textit{requer pequenas melhorias}; +: \textit{requer grandes melhorias}.} 
\end{tabular}
\end{center}
\end{table}

\end{landscape}

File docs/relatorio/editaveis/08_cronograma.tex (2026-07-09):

\begin{landscape}

\chapter{Cronograma} 

\begin{table}[H]
\begin{center}
\caption{Cronograma geral.}
\label{tab:cronograma-geral}
\begin{tabular}{|c|c|c|}
\hline
\textbf{Geral}          & \textbf{Previsto} & \textbf{Realizado} \\ \hline
Início do projeto       & 08/04/2026        & 08/04/2026         \\ \hline
Fim do projeto          & 08/07/2026        & 08/07/2026                \\ \hline
\end{tabular}
\end{center}
\end{table}

\begin{center}
\begin{footnotesize}
\begin{longtable}{|p{6.5cm}|c|c|c|c|c|p{4cm}|}
\caption{Cronograma consolidado por fase de atividade.} \label{tab:cronograma} \\

\hline
\textbf{Atividade} & \textbf{Início Prev.} & \textbf{Início Real.} & \textbf{Fim Prev.} & \textbf{Fim Real.} & \textbf{Predec.} & \textbf{Responsáveis} \\ \hline
\endfirsthead

\multicolumn{7}{c}%
{{\bfseries Tabela \thetable{} -- continuação da página anterior}} \\
\hline
\textbf{Atividade} & \textbf{Início Prev.} & \textbf{Início Real.} & \textbf{Fim Prev.} & \textbf{Fim Real.} & \textbf{Predec.} & \textbf{Responsáveis} \\ \hline
\endhead

\hline \multicolumn{7}{|r|}{{Continua na próxima página...}} \\ \hline
\endfoot

\hline
\endlastfoot

SW - 1 - Planejamento e Setup Inicial & 15/04/2026 & 15/04/2026 & 27/04/2026 & 09/05/2026 & --- & Equipe SW \\ \hline
SW - 2 - Modelagem e Estruturação Web & 30/04/2026 & 07/05/2026 & 11/05/2026 & 11/05/2026 & SW-1 & Equipe SW \\ \hline
SW - 3 - Integração Embarcada e Navegação & 11/06/2026 & 29/06/2026 & 28/06/2026 & 08/07/2026 & SW-1, HW-3 & Equipe SW \\ \hline
SW - 4 - Funcionalidades Web e Histórico & 28/05/2026 & 30/05/2026 & 08/06/2026 & 02/06/2026 & SW-2 & Equipe SW \\ \hline
SW - 5 - Integração Contínua e Testes & 11/06/2026 & 30/05/2026 & 22/06/2026 & 04/06/2026 & SW-4 & Equipe SW \\ \hline
SW - 6 - Validação Final e Documentação & 25/06/2026 & 08/07/2026 & 06/07/2026 & 08/07/2026 & SW-5 & Equipe SW \\ \hline

HW - 1 - Projeto Teórico e Diagramas & 15/04/2026 & 08/05/2026 & 30/04/2026 & 11/05/2026 & --- & Equipe HW \\ \hline
HW - 2 - Montagem Física e Movimento & 30/04/2026 & 03/06/2026 & 14/05/2026 & 05/06/2026 & HW-1 & Equipe HW \\ \hline
HW - 3 - Instalação e Ajuste de Sensores & 14/05/2026 & 01/06/2026 & 28/05/2026 & 05/06/2026  & HW-2 & Equipe HW \\ \hline
HW - 4 - Integração Geral e Testes Práticos & 28/05/2026 & 05/06/2026 & 11/06/2026 & 08/06/2026 & HW-3 & Equipe HW \\ \hline

EST - 1 - Modelagem CAD e Planejamento & 15/04/2026 & 20/04/2026 & 11/05/2026 & 10/05/2026 & --- & Equipe EST \\ \hline
EST - 2 - Fabricação e Impressão 3D & 30/04/2026 & 20/05/2026 & 07/06/2026 & 03/06/2026 & EST-1 & Equipe EST \\ \hline
EST - 3 - Verificação e Lições Aprendidas & 07/06/2026 & 07/07/2026 & 27/06/2026 & 08/07/2026 & EST-2 & Equipe EST \\ \hline

EN - 1 - Dimensionamento e Fonte & 15/04/2026 & 24/04/2026 & 11/05/2026 & 29/04/2026 & --- & Equipe EN \\ \hline
EN - 2 - Regulação e Monitoramento & 14/05/2026 & 01/06/2026 & 08/06/2026 & 08/06/2026 & EN-1 & Equipe EN \\ \hline
EN - 3 - Testes de Autonomia e Ensaio & 11/06/2026 & 01/06/2026 & 06/07/2026 & 06/07/2026 & EN-2 & Equipe EN \\ \hline

\end{longtable}
\end{footnotesize}
\end{center}

\begin{table}[H]
\begin{center}
\caption{Justificativas para atrasos ou não-conclusão de atividades.}
\label{tab:justificativas-cronograma}
\begin{tabular}{|c|c|} \hline
\textbf{Atividade} & \textbf{Justificativa}  \\ \hline 
    SW-1.1 a SW-2.5 &
    Atraso no início devido à curva de aprendizado das ferramentas de simulação e setup. \\ \hline
    HW-1.1 a HW-1.5 &
    Ajuste de cronograma para alinhar com a entrega de componentes eletrônicos. \\ \hline
    SW-3 &
    Replanejada para a sprint-5: depende do hardware (sensores e chassi) em finalização pela equipe de Hardware. \\ \hline
\end{tabular}
\end{center}
\end{table}

\end{landscape}

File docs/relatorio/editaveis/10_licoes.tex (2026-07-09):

\chapter{Lições Aprendidas}

O projeto Micromouse, da disciplina Projeto Integrador 1 (PI1), proporcionou  valiosas lições
para o desenvolvimento de futuros projetos interdisciplinares. A integração entre diversas áreas
das Engenharias de Software, Aeroespacial, Eletrônica, Energia e Automotiva, demonstrou o potencial da 
colaboração multidisciplinar.

Este capítulo documenta as lições aprendidas pela equipe ao longo do projeto, abordando desde a análise do cenário até os desafios de execução, visando evitar a repetição de falhas e otimizar processos em projetos futuros.

\section{Análise SWOT}

\begin{table}[ht]
% \label{tab:swot}
\centering
\caption{Análise SWOT do produto.}
\begin{tabular}{|c|c|c|} \hline
 & \textbf{Pontos fortes} & \textbf{Pontos fracos}  \\ \hline 
    {\parbox{0.1\textwidth}{ \textbf{Fatores \\ internos}}}  &
    {\parbox{0.4\textwidth}{ Forças: 
        \begin{itemize}
            \item Respeito e colaboração interdisciplinar, com subgrupos se ajudando ativamente.
            \item Resiliência da equipe diante da necessidade de troca de componentes.
            \item Decisão de projeto robusta com a utilização de chassi em dois andares.
        \end{itemize} }} & 
    {\parbox{0.4\textwidth}{ Fraquezas:
        \begin{itemize}
            \item Falha de comunicação e dificuldade na integração entre as subequipes.
            \item Desorganização no cumprimento de prazos, sobretudo na entrega do chassi.
            \item Desequilíbrio na distribuição de tarefas entre os integrantes do grupo.
        \end{itemize} }}\\ \hline
    {\parbox{0.1\textwidth}{ \textbf{Fatores \\ externos}}}  &
    {\parbox{0.4\textwidth}{ Oportunidades:
        \begin{itemize}
            \item Aprimoramento de \textit{soft skills} vinculadas à gestão de projetos.
            \item Aprendizado técnico prático em áreas até então desconhecidas pelos membros.
            \item Enriquecimento sistêmico através de ambiente multidisciplinar entre engenharias.
        \end{itemize} }} & 
    {\parbox{0.4\textwidth}{ Ameaças:
        \begin{itemize}
            \item Dificuldade e atrasos no fornecimento de recursos estruturais para o robô.
            \item Competição de tempo dos alunos devido aos compromissos com outras disciplinas.
            \item Riscos de falha no projeto causados pela sobrecarga de alguns integrantes.
        \end{itemize} }}\\ \hline
\end{tabular}
\label{tab:swot}
\end{table}

\section{Planejado x realizado}
\subsection{Objetivos}
Os objetivos do projeto foram plenamente alcançados. O micromouse demonstrou autonomia e eficácia na resolução do labirinto durante a apresentação 
final, validando a aplicação prática do algoritmo de navegação. A integração física e lógica entre os subsistemas de estrutura, eletrônica e firmware
funcionou de maneira harmônica, garantindo leituras estáveis dos sensores e respostas dos motores em tempo real. Essa conclusão com sucesso consolidou
o aprendizado prático da equipe e superou os gargalos de comunicação e atrasos enfrentados nas etapas iniciais de desenvolvimento.

\subsection{Prazos}

Ocorreram atrasos pontuais, sobretudo pela alta dependência entre as equipes e na entrega do chassi final utilizado. Isso gerou uma concentração do trabalho
do subgrupo de hardware e software na reta final do semestre em poucos integrantes.

\subsection{Orçamento}

O projeto foi executado com um custo financeiro menor que o inicialmente estipulado. Essa economia foi possível graças ao esforço da equipe no reaproveitamento de materiais
já existentes e no uso de componentes reciclados para a estrutura do labirinto utilizado nos testes da equipe. No entanto, houve a necessidade de troca de bateria algumas
vezes no decorrer do semestre.

\subsection{Escopo}

O projeto atendeu o escopo definido pelos requisitos da disciplina. Todas as funcionalidades e requisitos foram alcançados e o micromouse passou na avaliação final
(resolver dois labirintos 4x4 e um 8x8), obtendo a aprovação dos professores. Apesar de alguns atrasos em tarefas dentro do projeto, ele respeitou o tempo da entrega
final definido no cronograma da disciplina.

\section{Projeto}
\subsection{Pontos fortes}
\begin{enumerate}
    \item A liberdade de escolha dos membros em qual equipe atuar, facilitou a execução e resolução das atividades devido a familiaridade com a área.
    \item A impressão de um protótipo para testes permitiu que o grupo pudesse realizar ajustes e otimizações estruturais do micromouse.
    \item O uso de ferramentas já conhecidas (GitHub, LaTeX) por boa parte da equipe evitou uma grande curva de aprendizado. 
    \item Fazer múltiplos testes em todas as aulas e comunicar o grupo sobre o andamento nos deixou mais preparados para a apresentação.
\end{enumerate}
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

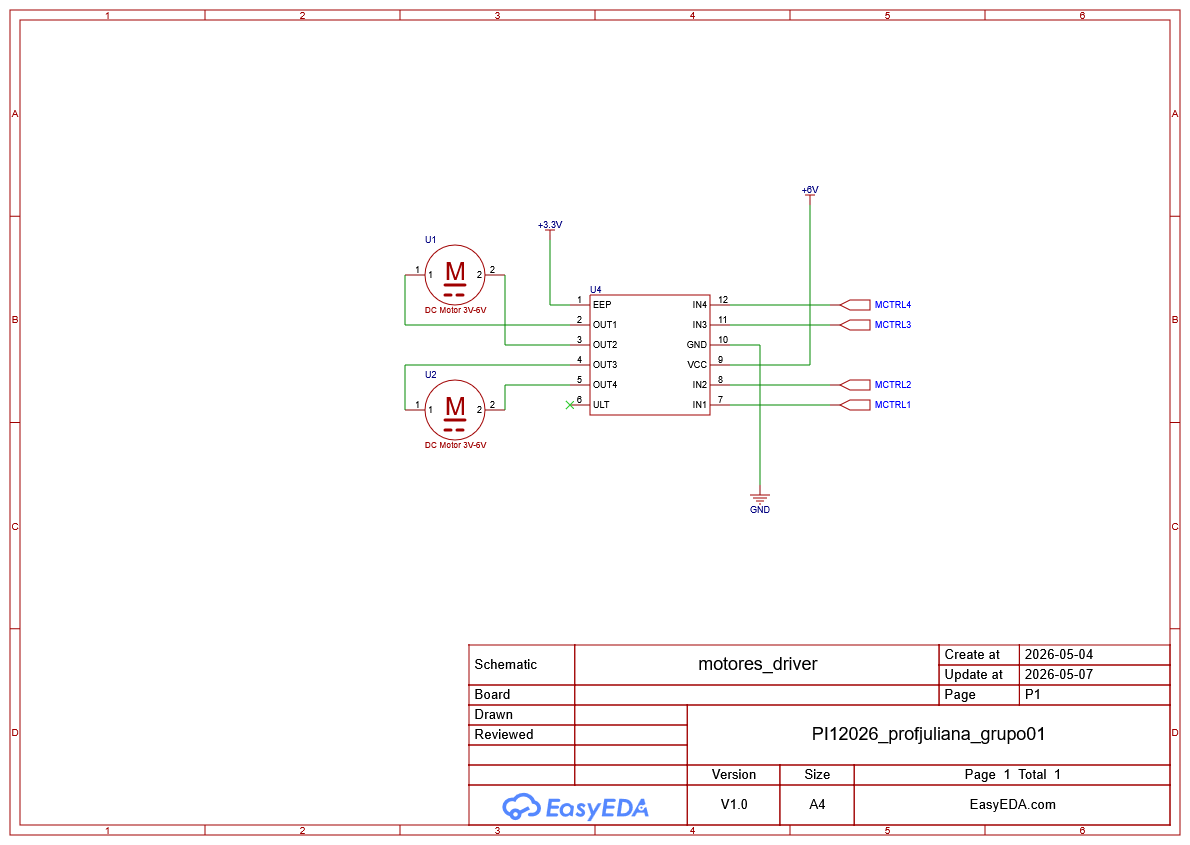
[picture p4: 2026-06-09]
docs/relatorio/figuras/SCH_motores_driver_1-P1_2026-06-08.png

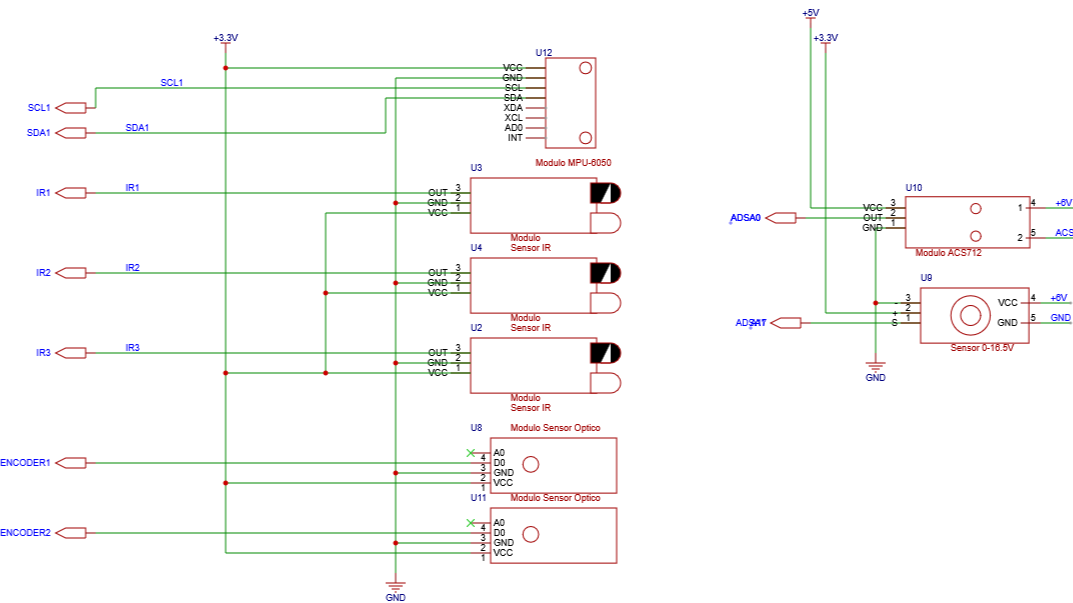
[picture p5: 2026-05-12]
docs/relatorio/figuras/SCH_sensores_1-P1_2026-05-11.png

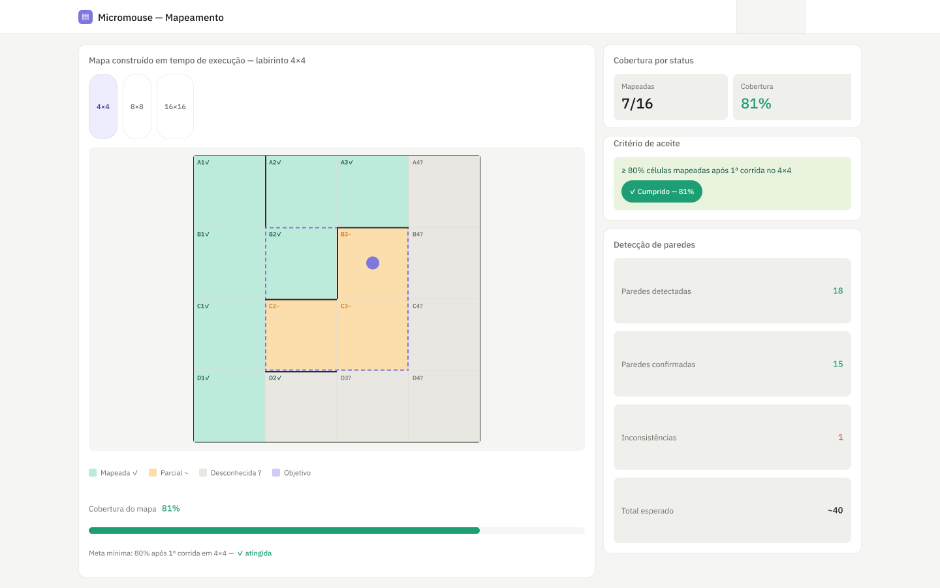
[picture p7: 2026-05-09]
docs/relatorio/figuras/HU02–Mapeamento incremental.png

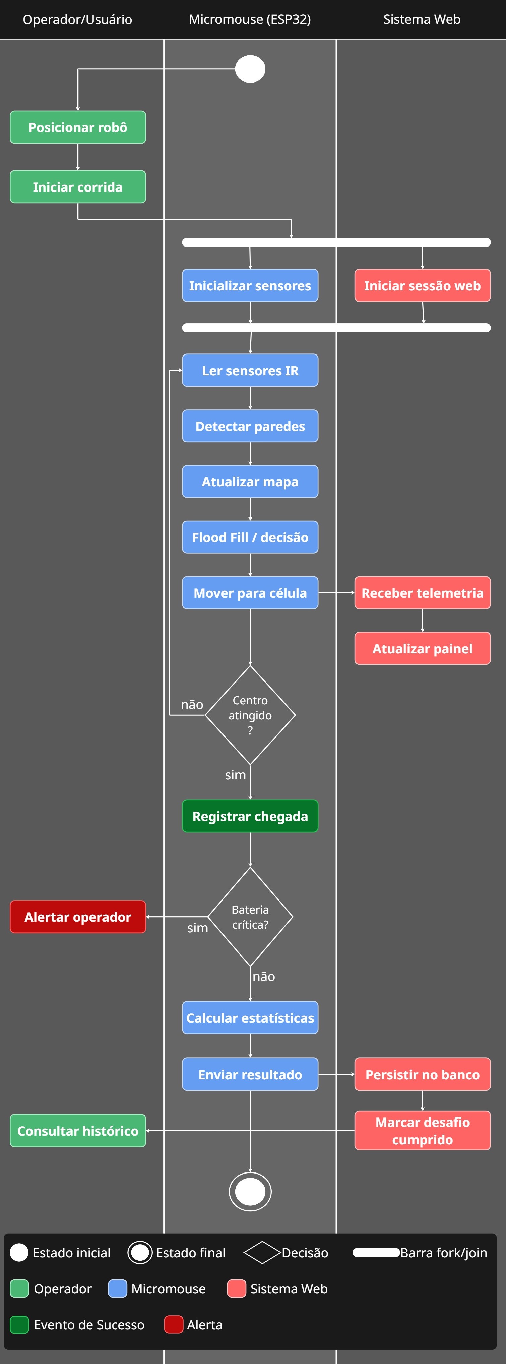
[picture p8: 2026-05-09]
docs/relatorio/figuras/diagrama_atividades_uml.jpg

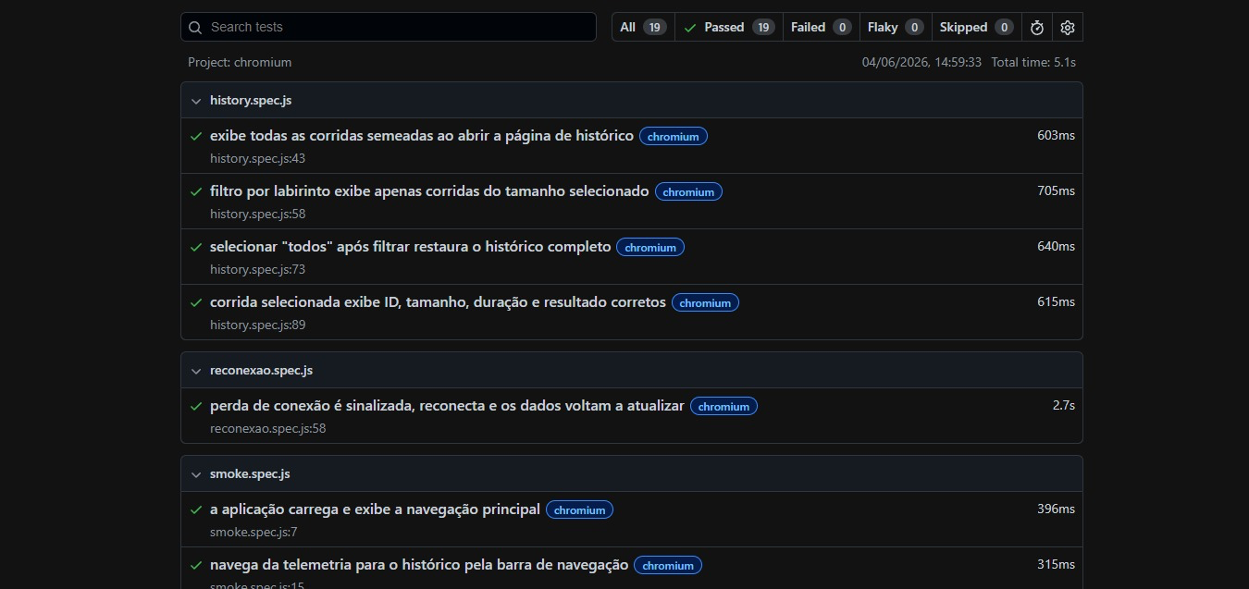
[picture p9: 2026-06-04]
docs/relatorio/figuras/e2e_playwright.png

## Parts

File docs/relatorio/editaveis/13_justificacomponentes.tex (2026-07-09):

\section{Diagramas de \textit{hardware}}

\subsection{Diagrama de Blocos}

\begin{figure}
    \centering
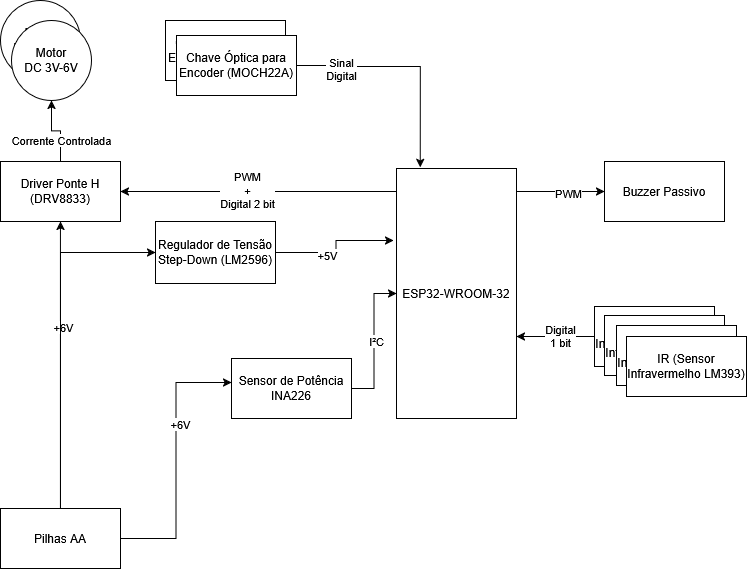
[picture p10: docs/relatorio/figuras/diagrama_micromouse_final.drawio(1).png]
    
    \caption{Diagrama de blocos dos componentes eletrônicos do \textit{micromouse}}
    \label{fig:diag_hw}
\end{figure}

\subsection{Esquematico}

\begin{figure}
    \centering
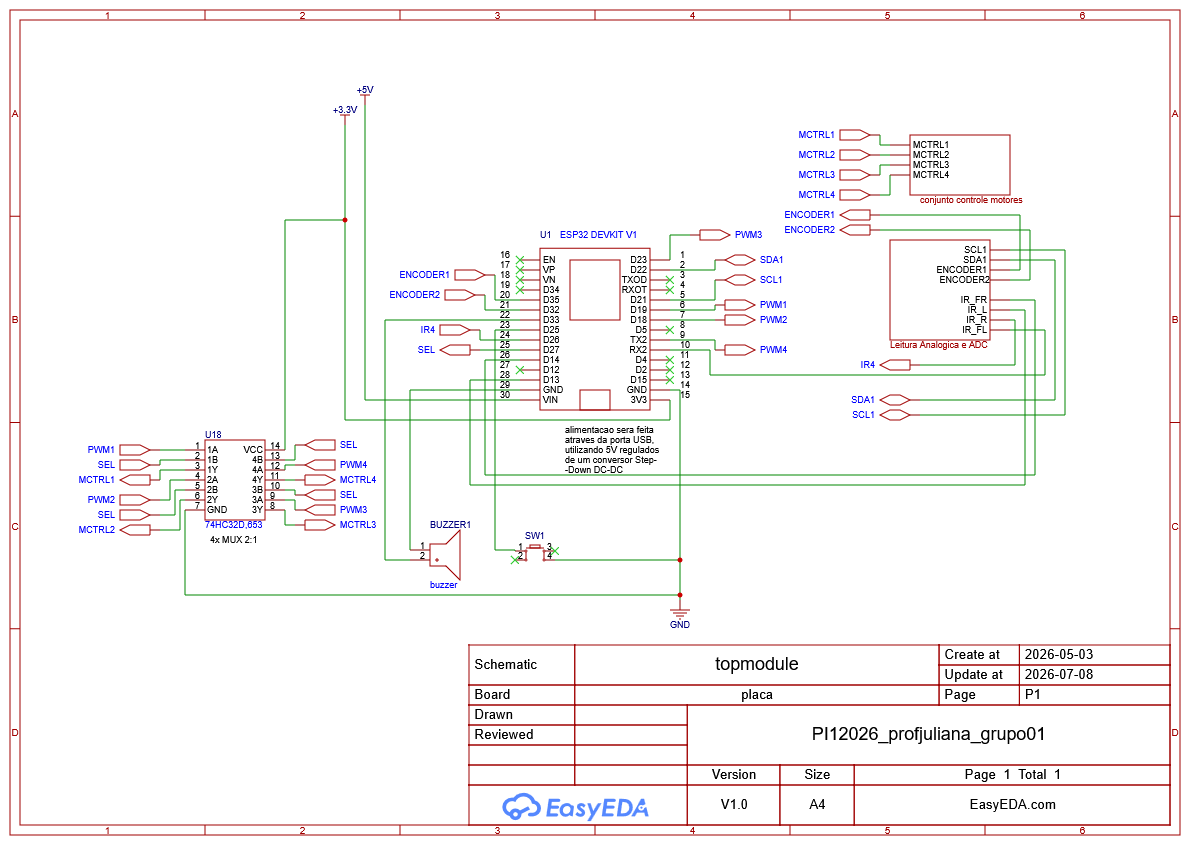
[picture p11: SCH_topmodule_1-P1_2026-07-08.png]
    
    \caption{Representação da Ligação dos Componentes no Microcontrolador}
    \label{fig:esq_topmodule}
\end{figure}

\begin{figure}
    \centering
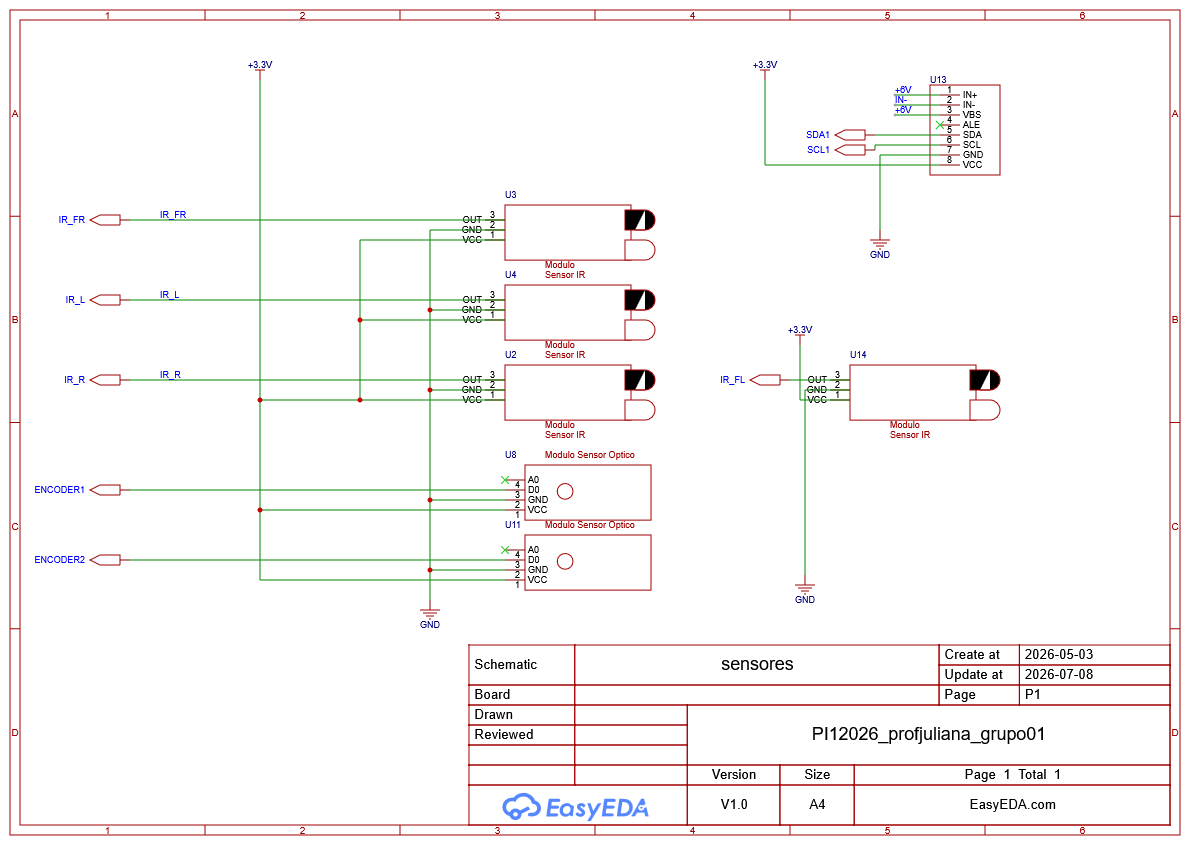
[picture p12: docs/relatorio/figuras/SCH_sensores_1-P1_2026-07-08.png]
    
    \caption{Representação Esquemática dos Sensores}
    \label{fig:esq_sensores}
\end{figure}

\begin{figure}
    \centering
    
    \caption{Representação Esquemática do Driver e Motores}
    \label{fig:esq_motores}
\end{figure}

\begin{figure}
    \centering
    
    \caption{Representação Esquemática da Alimentação do \textit{Micromouse}}
    \label{fig:esq_alimentacao}
\end{figure}

\section{Justificativa da escolha dos componentes de \textit{hardware}}
\label{sec:justificativa-componentes}

Esta seção apresenta a justificativa técnica para a seleção de cada componente utilizado no projeto, considerando requisitos funcionais, disponibilidade, custo e compatibilidade com a arquitetura geral do sistema.

\subsection{ESP32-WROOM-32}

O microcontrolador ESP32-WROOM-32 foi selecionado por oferecer capacidade de processamento adequada para aplicações embarcadas, além de integração nativa com comunicação Wi-Fi e Bluetooth, possibilitando futura expansão do sistema. Segundo o trabalho apresentado no CONICT do IFSP, o ESP32 apresenta boa compatibilidade com sistemas robóticos devido à sua quantidade de portas de entrada e saída, baixo custo e facilidade de integração com sensores e atuadores. Além disso, sua operação em 3,3 V torna o componente compatível com módulos eletrônicos modernos utilizados no projeto.

Artigo base: \cite{oliveira2024_esp32_roboticar}

\subsection{Sensor Infravermelho (LM393)}

O sensor infravermelho LM393 foi selecionado para detecção de paredes e obstáculos do labirinto. Este módulo integra um LED infravermelho, um fototransistor e circuito de pré-processamento de sinais analógicos, oferecendo facilidade de implementação. O LM393 apresenta características técnicas adequadas para a aplicação: baixo consumo de energia (menos de 1 mA), ampla faixa de operação de tensão (2V a 36V), ângulo de difusão de 35° e alcance de 2 a 30 cm. Além disso, o sensor retorna sinais digitais ao microcontrolador, facilitando o processamento de dados. Por ser uma solução econômica e apresentar baixa complexidade de programação, o LM393 é apropriado para contextos educacionais e projetos com orçamento limitado.

Artigo base: \cite{lima2025_micromouse_lm393}

% \subsection{Bússola Magnetômetro (GY-271 HMC5883L)}

% O módulo GY-271 com magnet\^ometro HMC5883L foi escolhido por sua praticidade na identifica\c{c}\~ao da orienta\c{c}\~ao absoluta do rob\^o durante a navega\c{c}\~ao. No contexto do Micromouse, esse tipo de sensor pode ser usado como apoio para ajustar a virada do rob\^o ap\'os manobras de 90\textdegree\ ou 180\textdegree, ajudando a reduzir desvios acumulados e a confirmar se a mudan\c{c}a de dire\c{c}\~ao ocorreu de forma consistente com o comando enviado aos motores. Al\'em disso, por se tratar de um m\'odulo pequeno, de f\'acil integra\c{c}\~ao via I\textsuperscript{2}C e baixo consumo, sua utiliza\c{c}\~ao favorece a montagem do sistema embarcado sem aumento significativo de complexidade.

% Para garantir que a leitura n\~ao sofra interfer\^encia indevida dos motores, da ponte H ou de outros elementos do chassi, devem ser executados testes pr\'aticos com o rob\^o parado e tamb\'em em movimento. Os testes recomendados incluem: medi\c{c}\~ao da leitura de refer\^encia com o sistema desligado; compara\c{c}\~ao das leituras com motores desligados e ligados em diferentes rota\c{c}\~oes; valida\c{c}\~ao da varia\c{c}\~ao angular durante curvas conhecidas; e repeti\c{c}\~ao das medi\c{c}\~oes ap\'os altera\c{c}\~oes de posi\c{c}\~ao do sensor no chassi. Caso haja oscila\c{c}\~ao excessiva, o sensor deve ser reposicionado e a calibra\c{c}\~ao refeita at\'e que as leituras permane\c{c}am est\'aveis o suficiente para apoiar a corre\c{c}\~ao de orienta\c{c}\~ao do rob\^o.

% Fonte: \cite{eletrogate_bussola}

\subsection{Driver Ponte H (DRV8833)}

O driver DRV8833 foi escolhido por permitir o controle independente de dois motores DC, oferecendo controle de velocidade e direção através de PWM. O componente apresenta baixo consumo energético, suporte a tensões compatíveis com o ESP32 e mecanismos internos de proteção contra sobrecorrente e superaquecimento, aumentando a segurança do sistema. Conforme descrito na documentação técnica da Texas Instruments e em aplicações embarcadas similares, o DRV8833 é amplamente utilizado em robôs móveis compactos devido à sua eficiência energética e tamanho reduzido.

Artigo base: \cite{oliveira2024_esp32_roboticar}

\subsection{Regulador de Tensão Step-Down (LM2596)}

O módulo regulador LM2596 foi adotado para garantir estabilidade na alimentação elétrica do sistema, realizando a conversão eficiente da tensão fornecida pela bateria para níveis adequados aos demais componentes eletrônicos. De acordo com o artigo do CONICT do IFSP, o LM2596 é amplamente empregado em sistemas embarcados por apresentar boa eficiência energética, baixo custo e facilidade de integração. Sua utilização contribui para a proteção dos circuitos e para o funcionamento estável do microcontrolador e dos sensores.

Artigo base: \cite{oliveira2024_esp32_roboticar}

\subsection{Chave Óptica para Encoder (MOCH22A)}

O sensor óptico MOCH22A foi escolhido para a detecção de velocidade e posição das rodas, pois permite gerar pulsos a partir da passagem das marcas do disco encoder acoplado ao eixo do motor. A partir da contagem desses pulsos em intervalos de tempo conhecidos, o sistema consegue estimar a rotação do motor e, com isso, também estimar variações de velocidade e rotação do rob\^o durante manobras e deslocamentos no labirinto. Com esses dados, se faz uso de equações de movimento conhecidas para determinar a posição relativa do robô e seu deslocamento (CORKE, 2011). Esse tipo de realimenta\c{c}\~ao \^e importante para o controle mais preciso da locomoc\~ao, principalmente em trajet\'orias curtas e corre\c{c}\~oes finas de movimento.

Embora a refer\^encia base utilize Arduino, o princ\'ipio de funcionamento \^e diretamente adapt\'avel ao ESP32, que tamb\'em possui suporte a interrup\c{c}\~oes e opera\c{c}\~ao adequada com leitura digital de pulsos. Dessa forma, o MOCH22A contribui para o sistema embarcado ao fornecer feedback confi\'avel de rota\c{c}\~ao, com baixo custo, montagem simples e boa integra\c{c}\~ao com a l\'ogica de controle do motor.

Fontes:~\cite{makerhero_moch22a}, \cite{petercorke}

\subsection{Sensor de Potência (INA226)}

O sensor de potência INA226 foi escolhido para substituir os sensores individuais de tensão e corrente e realizar o monitoramento do consumo energético com mais precisão e economia de espaço. Este sensor realiza suas leituras e as armazena em registradores próprios no chip do sensor, bastando apenas selecionar o registrador da grandeza desejada para obter a sua leitura. Isso é um fator decisivo para a gestão de processamento do projeto. Além disso, o sensor trabalha com comunicação I²C, possibilitando comunicação rápida e robusta com a ESP32.

\subsection{Porta Lógica 74HC32 (OU lógico)}

Este Circuito Integrado foi escolhido com a finalidade de realizar a multiplexação das entradas do driver DRV8833, visto que, para obter o freio ativo deste, era necessário que as entradas fossem 1 lógico (ou "high"). Assim, multiplexando as entradas da ponte H, evita-se que os GPIOs da ESP tenham de ser reconfigurados frequentemente entre GPIOs PWM e GPIOs comuns, economizando processamento e linhas de código desnecessárias. 

\subsection{Buzzer Passivo}

O buzzer passivo foi escolhido para a sinalização sonora por apresentar menor dimens\~ao e peso em rela\c{c}\~ao ao buzzer ativo, o que contribui para a redu\c{c}\~ao do volume e da massa total do sistema. Al\'em disso, seu uso permite um projeto de acionamento mais simples do ponto de vista de integra\c{c}\~ao ao conjunto eletr\'onico, e seu custo inferior em compara\c{c}\~ao ao buzzer ativo torna a solu\c{c}\~ao mais econ\^omica para o projeto.

Fonte: \cite{makerhero_buzzer}

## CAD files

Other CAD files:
mec/chassi/arquivosCAD/2andar.CATPart
mec/chassi/arquivosCAD/Conversor.CATPart
mec/chassi/arquivosCAD/Driver Motor.CATPart
mec/chassi/arquivosCAD/ESP32.CATPart
mec/chassi/arquivosCAD/Motor.CATPart
mec/chassi/arquivosCAD/Part8.CATPart
mec/chassi/arquivosCAD/Product6.CATProduct
mec/chassi/arquivosCAD/Protoboard.CATPart
mec/chassi/arquivosCAD/Remi.CATProduct
mec/chassi/arquivosCAD/Roda.CATPart
mec/chassi/arquivosCAD/Sensor IR.CATPart
mec/chassi/arquivosCAD/StepDown.CATPart
mec/chassi/arquivosCAD/chassi.CATPart
mec/labirinto/arquivosCAD/Labirinto.CATProduct
mec/labirinto/arquivosCAD/MeioChao.CATPart
mec/labirinto/arquivosCAD/ParedeGrande.CATPart
mec/labirinto/arquivosCAD/ParedeGrandeTeto.CATPart
mec/labirinto/arquivosCAD/ParedeLabMenor.CATPart
mec/labirinto/arquivosCAD/ParedeMedio.CATPart
mec/labirinto/arquivosCAD/ParedeMedioTeto.CATPart
mec/labirinto/arquivosCAD/Paredinha.CATPart
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

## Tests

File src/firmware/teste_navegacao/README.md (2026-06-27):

# Teste de Navegação para Robô Micromouse com ESP32

Projeto desenvolvido em **ESP-IDF** para validar a integração dos principais módulos de um robô Micromouse, incluindo controle dos motores, odometria, encoders, sensores infravermelhos e interface de usuário por botão e buzzer.

---

## Objetivo

Este projeto tem como finalidade testar a integração entre os módulos responsáveis pela navegação do robô antes da implementação do algoritmo completo de exploração do labirinto.

Atualmente o firmware realiza testes de:

* Inicialização do hardware;
* Controle dos motores;
* Leitura dos encoders;
* Atualização da odometria;
* Inicialização dos sensores infravermelhos;
* Seleção do tipo de labirinto através de botão externo;
* Reprodução de sinais sonoros utilizando buzzer;
* Comunicação entre interrupções e tarefas do FreeRTOS utilizando Task Notifications.

O suporte ao monitoramento de potência utilizando o INA226 já está parcialmente implementado, porém permanece comentado durante esta etapa de desenvolvimento.

---

# Hardware utilizado

* ESP32
* Driver de motores DRV8833
* 2 motores DC com encoder óptico
* 4 sensores infravermelhos
* Buzzer passivo
* Botão de seleção
* (Opcional) INA226 para monitoramento de corrente e tensão

---

# Estrutura do projeto

Os principais módulos utilizados são:

```
main/
│
├── main.c
├── m_driver
├── movimentacao
├── encoder
├── odometria
├── infrared
└── power_module (em desenvolvimento)
```

### Descrição dos módulos

| Módulo | Função |
| --- | --- |
| `m_driver` | Controle dos motores via MCPWM |
| `encoder` | Leitura dos encoders utilizando PCNT |
| `movimentacao` | Movimentos básicos do robô |
| `odometria` | Atualização da posição estimada |
| `infrared` | Leitura dos sensores IR e tratamento de interrupções |
| `power_module` | Interface para o INA226 (temporariamente desabilitada) |

---

# Funcionamento

Durante a inicialização o firmware executa:

1. Configuração do botão de seleção;
2. Configuração do buzzer;
3. Inicialização dos encoders;
4. Inicialização do driver dos motores;
5. Inicialização dos sensores infravermelhos;
6. Inicialização da odometria;
7. Criação da tarefa responsável pelo tratamento do botão.

Após inicializado, o firmware realiza testes periódicos de movimentação enquanto permanece apto a responder ao botão externo.

## Comportamento Esperado
O micromouse deverá realizar os bips de inicialização e, após alguns segundos, começar a avançar o equivalente a uma célula do labirinto (aprox. 18cm - 2,4cm). Ele deverá repetir esse comportamento até que os sensores frontais acusem algum obstáculo. Nesse momento, ele realizará a rotina de interrupção que deverá alterar a trajetória do robô de maneira adequada.

---

# Seleção do labirinto

O botão conectado ao GPIO configurado como entrada com interrupção permite alternar entre os modos de operação.

Tipos disponíveis:

* 4×4
* 8×8

Cada seleção é indicada por uma sequência sonora diferente reproduzida pelo buzzer.

---

# Interrupções

O projeto utiliza interrupções de GPIO para:

* Botão de seleção
* Sensores infravermelhos

As ISRs executam apenas o código mínimo necessário e sinalizam tarefas do FreeRTOS através de **Task Notifications**, reduzindo o tempo gasto em contexto de interrupção.

---

# Recursos utilizados da ESP-IDF

* FreeRTOS
* GPIO
* LEDC
* MCPWM
* PCNT
* Task Notifications
* ISR Service

---

# Funcionalidades implementadas

* [x] Controle dos motores
* [x] Leitura dos encoders
* [x] Odometria básica
* [x] Sensores infravermelhos
* [x] Buzzer
* [x] Botão com interrupção
* [x] Comunicação ISR → Task
* [ ] Integração completa do INA226
* [ ] Algoritmo de exploração do labirinto
* [ ] Planejamento de trajetória
* [ ] Resolução automática do labirinto

---

# Compilação

Projeto desenvolvido utilizando **ESP-IDF**.

```
idf.py build
idf.py flash
idf.py monitor
```

---

# Observações

Este repositório representa uma etapa intermediária do desenvolvimento do robô, focada principalmente na integração entre hardware e software. A estrutura do código está sendo organizada em módulos independentes para facilitar manutenção, reutilização e expansão das funcionalidades.

O código continuará evoluindo com a implementação do algoritmo de navegação e da estratégia completa para competições de Micromouse.

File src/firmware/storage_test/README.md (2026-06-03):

# Testes de Armazenamento Local (NVS & SPIFFS) - Micromouse

Este subdiretório contém os códigos para os testes de armazenamento local no microcontrolador ESP32 do robô Micromouse. O objetivo é demonstrar que o hardware é capaz de armazenar dados de configuração persistentes (via **NVS**) e leituras/telemetria de sensores (via **SPIFFS**).

---

## 📂 Estrutura do Diretório

* **`main/storage_test_main.c`**: Código-fonte em C (ESP-IDF) para rodar na placa física ESP32.
* **`simulate_storage.py`**: Script em Python que simula o comportamento exato de leitura e escrita das memórias NVS e SPIFFS localmente no seu computador.
* **`CMakeLists.txt` e `main/CMakeLists.txt`**: Arquivos de configuração do sistema de compilação CMake.

---

## 🐍 1. Executando a Simulação em Python (Sem a ESP Física)

Como você está sem a ESP física agora, o script `simulate_storage.py` simula as gravações e leituras de arquivos que o firmware faria.

### Passo a passo para rodar:

1. Abra o terminal na pasta deste teste:
   ```bash
   cd src/firmware/storage_test
   ```

2. Execute o script:
   ```bash
   python simulate_storage.py
   ```

3. O console mostrará:
   * **Cenário 1 (NVS):** Gravando `corrida_id = 3` e relendo para validar se o valor permanece íntegro.
   * **Cenário 2 (SPIFFS):** Gravando um payload de telemetria simulado em formato JSON, lendo a linha, efetuando o parse e validando os dados.

4. Ao final, o script perguntará se deseja testar o envio opcional para o backend FastAPI local (`s/n`). Se você tiver o backend rodando e configurado conforme o README do backend, pode digitar `s` para testar a comunicação.

---

## 🔌 2. Rodando na Placa ESP32 (Firmware Real)

Quando você estiver com o hardware físico em mãos, poderá compilar o firmware real.

### Tabela de Partições Customizada (Importante para SPIFFS)
Para que o sistema de arquivos SPIFFS monte com sucesso no hardware da ESP32, configuramos uma partição personalizada na memória flash do chip.
* **`partitions.csv`**: Define a partição de dados do tipo `spiffs` com tamanho de 1 MB.
* **`sdkconfig.defaults`**: Garante que o processo de build do ESP-IDF ative automaticamente a opção de tabela de partições customizada (`CONFIG_PARTITION_TABLE_CUSTOM=y`) e a aponte para o nosso `partitions.csv`. Não é necessário configurar isso no `menuconfig` manualmente.

### Utilizando a Extensão do ESP-IDF no VS Code:
1. Abra o projeto no VS Code.
2. Certifique-se de que a extensão oficial do **ESP-IDF** da Espressif está instalada e configurada.
3. Clique no botão de seleção de target (barra inferior do VS Code) e escolha o chip correto (ex: `ESP32` ou `ESP32-S3`).
4. Clique em **Build** (ícone de engrenagem) para compilar o código. O ESP-IDF usará o `sdkconfig.defaults` para gerar a configuração de partições apropriada automaticamente.
5. Conecte a placa via USB, selecione a porta COM correspondente e clique em **Flash** (ícone de raio) para gravar no chip.
6. Clique em **Monitor** (ícone de monitor) para abrir o terminal serial (UART).

### Saída Esperada no Monitor Serial:
Você deverá ver logs claros no terminal semelhantes a este:
```text
I (312) STORAGE_TEST: ==================================================
I (312) STORAGE_TEST: Iniciando Testes de Armazenamento Local - Micromouse
I (322) STORAGE_TEST: ==================================================
I (332) STORAGE_TEST: === [INICIANDO TESTE NVS] ===
I (342) STORAGE_TEST: Gravando corrida_id = 3 na NVS...
I (382) STORAGE_TEST: [NVS TEST] Aprovado: Gravado=3, Lido=3
I (1392) STORAGE_TEST: === [INICIANDO TESTE SPIFFS] ===
I (1412) STORAGE_TEST: SPIFFS montado: Total: 956 KB, Usado: 1 KB
I (1412) STORAGE_TEST: Abrindo arquivo /spiffs/telemetry.json para gravação...
I (1422) STORAGE_TEST: Escrevendo leituras no arquivo: {"posicao_x":5,"posicao_y":7,"nivel_bateria":84.5,"velocidade":0.42}
I (1432) STORAGE_TEST: Arquivo fechado.
I (1432) STORAGE_TEST: Reabrindo arquivo /spiffs/telemetry.json para leitura...
I (1442) STORAGE_TEST: Dados lidos do SPIFFS: {"posicao_x":5,"posicao_y":7,"nivel_bateria":84.5,"velocidade":0.42}
I (1452) STORAGE_TEST: SPIFFS desmontado.
I (1452) STORAGE_TEST: [SPIFFS TEST] Aprovado: Leituras dos sensores gravadas e validadas com sucesso!
I (1462) STORAGE_TEST: ==================================================
I (1472) STORAGE_TEST: Resumo dos Testes de Armazenamento:
I (1472) STORAGE_TEST:   Teste NVS (Dados Básicos):      PASSOU
I (1482) STORAGE_TEST:   Teste SPIFFS (Dados Sensores): PASSOU
I (1492) STORAGE_TEST: ==================================================
```

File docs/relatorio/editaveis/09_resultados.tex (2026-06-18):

\chapter{Testes de Verificação e Validação}

\section{Características Gerais}

Este capítulo tem como objetivo apresentar os procedimentos de verificação e validação aplicados aos subsistemas do projeto. A etapa de testes é fundamental para garantir que o robô atenda aos requisitos de projeto, navegando pelo labirinto de forma autônoma e eficiente. Para assegurar a repetibilidade e o rigor metodológico, cada experimento documentado a seguir detalha as hipóteses levantadas, as condições de contorno estabelecidas durante a execução, os resultados esperados, os materiais e métodos empregados, bem como a análise da precisão e acurácia das medidas obtidas.

\section{Testes da estrutura}

% \textcolor{red}{Apresentar com detalhes os testes feitos para conferir se os objetivos da estrutura foram atendidos, incluindo:}

% \begin{itemize}
%     \item \textcolor{red}{Imagem com todas as peças separadas da estrutura (carcaça) do veículo;}
%     \item \textcolor{red}{Imagem que apresente a estrutura já montada (sem necessidade de partes internas, como eletrônica ou motores);}
%     \item \textcolor{red}{Ilustração contemplando o carro montado virtualmente em alguma ferramenta de CAD, no intuito de verificar se as peças foram construídas e montadas em conformidade com o projeto.}
% \end{itemize}

Esta seção apresenta os testes realizados para verificar se a estrutura mecânica do micromouse atende aos requisitos definidos durante o projeto. Foram avaliados aspectos relacionados à montagem da carcaça do veículo e ao labirinto modular.

\subsection{Veículo Desmontado}

O chassi do micromouse foi projetado em CAD como uma peça única para ser fabricada em impressão 3D utilizando material PLA. Durante esta entrega, procedeu-se à fabricação e testes preliminares dessa versão.

\begin{figure}[H]
    \centering
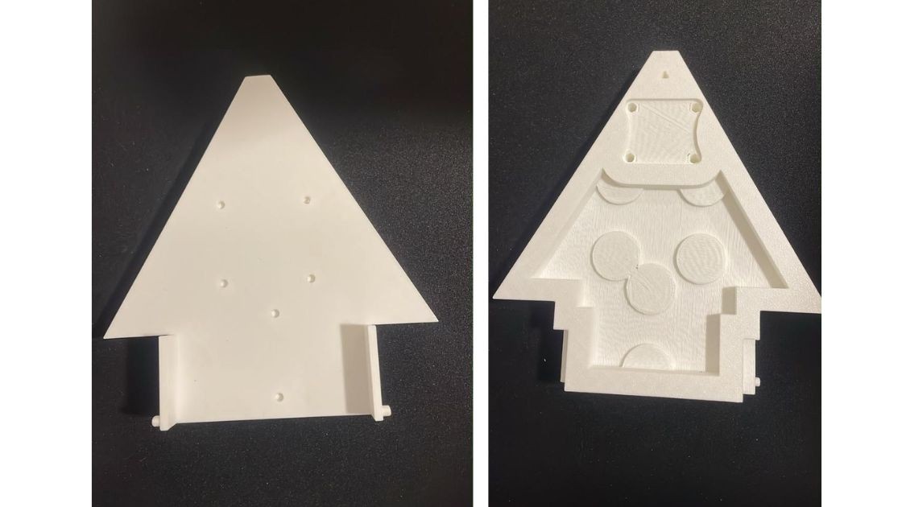
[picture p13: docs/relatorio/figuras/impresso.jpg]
    
    \caption{Chassi completo, peça única impressa em 3D.}
    \label{fig:chassi_impresso}
\end{figure}

A Figura \ref{fig:chassi_desmontado} apresenta os componentes estruturais que compõem a montagem do micromouse.

\begin{figure}[H]
    \centering
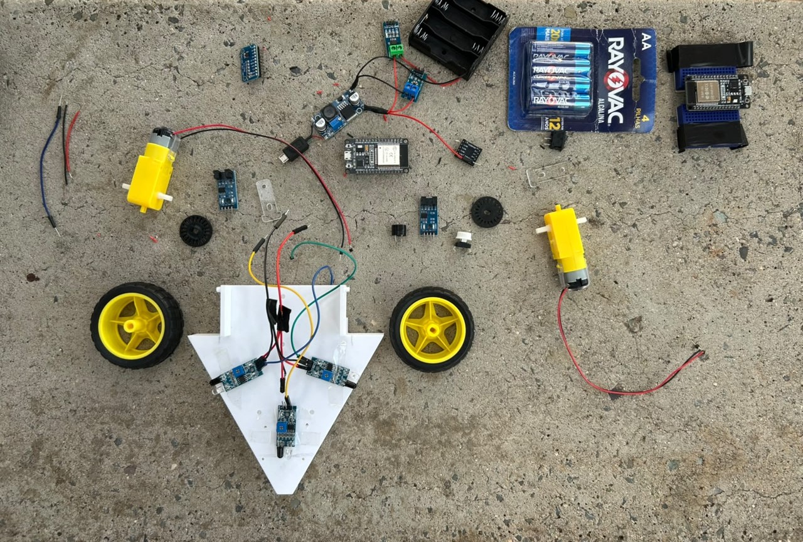
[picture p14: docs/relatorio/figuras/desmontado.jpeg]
    
    \caption{Componentes estruturais do micromouse.}
    \label{fig:chassi_desmontado}
\end{figure}

\subsubsection{Análise do protótipo em 3D}

O chassi em 3D apresentou problemas dimensionais durante a montagem: as dimensões finais da peça não atendiam completamente os limites esperados no projeto, principalmente em relação ao comprimento e altura que prejudicaram a performance dos sensores de proximidade. Constatou-se que a peça não atenderia aos requisitos de tamanho para competição.

Adicionalmente, o processo de impressão 3D gerou imperfeições nos encaixes destinados aos motores, exigindo pós-processamento (lixamento) para permitir o acoplamento adequado dos componentes. A elaboração de um novo protótipo em 3D, com ajustes dimensionais e reforço dos encaixes, está planejada para a próxima etapa do projeto.

\subsubsection{Validação funcional com chassi provisório}

Visando não comprometer a validação dos testes de montagem, conformidade e funcionalidade da estrutura durante esta etapa do projeto, foi utilizado um \textbf{chassi provisório em acrílico} que atende aos requisitos de encaixe dos componentes enquanto a versão final em 3D é otimizada. Este chassi permitiu validar o encaixe e acomodação de todos os componentes eletrônicos (bateria, motores, sensores, protoboard), a estabilidade estrutural durante operação e a confirmação de que a arquitetura projetada é viável

\subsection{Chassi Montado (Provisório em Acrílico)}

A Figura \ref{fig:chassi_montado_acrilico} apresenta o chassi provisório em acrílico montado com todos os componentes eletrônicos acoplados.

\begin{figure}[H]
    \centering
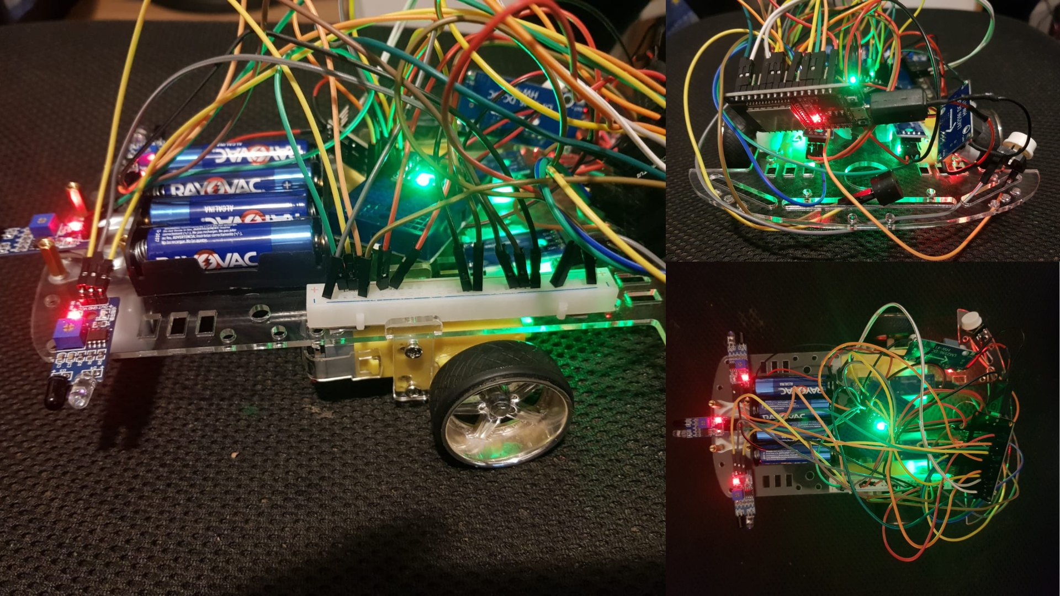
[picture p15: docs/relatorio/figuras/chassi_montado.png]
    
    \caption{Chassi provisório em acrílico completamente montado com componentes eletrônicos.}
    \label{fig:chassi_montado_acrilico}
\end{figure}

\subsection{Labirinto Modular}
O labirinto modular construído atende aos requisitos definidos no projeto para a validação do circuito do micromouse, oferecendo uma estrutura resistente e adequada aos ensaios de navegação do robô. Fabricado em madeira, o conjunto apresentou boa rigidez mecânica e respeitou as especificações dimensionais previstas, com células de $18\text{ cm}$ de lado, paredes de $5\text{ cm}$ de altura e $1{,}2\text{ cm}$ de espessura, totalizando uma área de $72\text{ cm} \times 72\text{ cm}$ em conformidade com o modelo projetado.

\begin{figure}[H]
    \centering
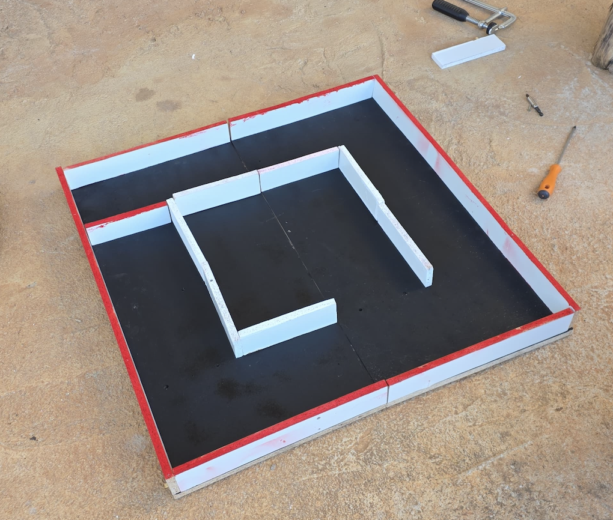
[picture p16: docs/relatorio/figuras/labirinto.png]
    
    \caption{Labirinto modular construído para os testes estruturais do micromouse.}
    \label{fig:labirinto_resultados}
\end{figure}

\section{Testes de \textit{hardware}}
\label{sec:testes_hardware}

Os testes de \textit{hardware} tiveram como objetivo verificar, em bancada, se o
conjunto embarcado do \textit{micromouse} estava apto a executar o \textit{firmware},
ler sensores, acionar motores, registrar dados e transmitir informações de
diagnóstico. Os ensaios foram realizados com a ESP32, sensores infravermelhos
digitais com comparador LM393, sensor INA226, encoders dos motores DC, driver
DRV8833 e monitoramento serial pelo ambiente ESP-IDF. As evidências completas dos
testes executados no terminal estão reunidas no
Apêndice~\ref{apendice_evidencias_testes_hardware}.

\subsection{Processamento}

Para validar o núcleo de processamento do robô, realizou-se um ensaio de bancada
com o microcontrolador isolado. O objetivo foi homologar o ambiente de
desenvolvimento e certificar que a placa estava apta a receber, armazenar e
executar os \textit{firmwares} desenvolvidos para o projeto.

A programação, configuração e validação foram realizadas no Visual Studio Code,
utilizando o ESP-IDF (Espressif IoT Development Framework) v6.0.1. A escolha do
ESP-IDF justifica-se pela necessidade de acesso aos recursos avançados da ESP32,
incluindo suporte ao FreeRTOS, gerenciamento de tarefas concorrentes, utilização
dos núcleos de processamento e acesso direto aos periféricos embarcados.

Como teste inicial de integridade, foi utilizado o exemplo oficial
\texttt{hello\_world}. O microcontrolador foi conectado ao computador via USB,
compilado com \texttt{idf.py build}, gravado na memória \textit{flash} com
\texttt{idf.py flash} e monitorado pela interface serial com
\texttt{idf.py monitor}. A compilação, gravação e execução ocorreram sem falhas,
e as mensagens exibidas no monitor serial confirmaram o funcionamento do
processador, da memória \textit{flash} e da comunicação serial. Assim, o núcleo
de processamento foi considerado aprovado para as etapas de integração com
sensores, atuadores e demais subsistemas embarcados.

\subsection{Sensores}

Foi implementada a leitura básica dos sensores infravermelhos digitais com LM393
utilizando a ESP32 em linguagem C com ESP-IDF. As leituras foram realizadas por
GPIOs configuradas como entradas digitais, permitindo detectar presença ou
ausência de obstáculos; saída igual a 0 indica presença, enquanto saída igual a 1
indica ausência. Os dados foram enviados via UART para monitoramento serial em
tempo real.

A validação dos sensores infravermelhos foi feita aproximando obstáculos em
diferentes distâncias para verificar a alteração do nível lógico na saída
digital. A calibração foi realizada pelo potenciômetro presente no módulo LM393,
permitindo ajustar a sensibilidade e a distância de detecção de acordo com a
necessidade do robô. Devido às dimensões do chassi e à necessidade de manter o
robô centralizado na célula, adotou-se a menor faixa de detecção estável obtida
na calibração.

Inicialmente, a taxa de amostragem utilizada foi de aproximadamente 500 ms entre
leituras. Essa configuração facilitou a validação funcional e a observação dos
dados transmitidos via UART. A taxa mostrou-se suficiente para os ensaios de
bancada, embora a navegação autônoma deva empregar leituras mais frequentes para
melhorar o tempo de resposta diante de obstáculos.

Também foram testados sensores associados à navegação e ao consumo elétrico. Os
encoders foram validados por meio da leitura de pulsos durante comandos de
movimentação e giro; o terminal registrou pulsos independentes para os lados
direito e esquerdo e ângulos calculados durante as manobras, conforme evidenciado
na Figura~\ref{fig:teste_valida_dados_encoder}. Para medição elétrica, o sensor
INA226 foi detectado no barramento I\textsuperscript{2}C no endereço
\texttt{0x44}, permitindo registrar tensão, corrente e potência do conjunto em
dois cenários: carrinho suspenso, com as rodas girando livremente e sem oposição
externa, e carrinho apoiado no chão, no qual os motores precisam vencer a inércia
do próprio robô para iniciar o movimento
(Figuras~\ref{fig:teste_potencia_motores_sem_esforco}
e~\ref{fig:teste_potencia_motores_com_esforco}).

O processamento básico dos sensores infravermelhos utiliza
\textit{thresholding} digital realizado pelo comparador LM393, que converte a
leitura analógica do módulo em níveis lógicos binários. Para as próximas etapas,
prevê-se a implementação de filtragem simples e \textit{debounce}, a fim de
reduzir oscilações e falsos acionamentos durante a movimentação do robô.

\subsection{Armazenamento}

Os testes de armazenamento local foram implementados no diretório
\path{src/firmware/storage\_test/}, com \textit{firmware} em C para ESP-IDF e
um simulador em Python. O objetivo foi validar dois mecanismos de persistência
do ESP32: a NVS (\textit{Non-Volatile Storage}), utilizada para dados básicos de
configuração, e o SPIFFS (\textit{SPI Flash File System}), utilizado para
persistência e validação de telemetria de sensores.

No teste de NVS, o sistema grava e lê novamente um valor de referência,
verificando a integridade do dado persistido. A execução local pelo simulador
\texttt{simulate\_storage.py} foi considerada aprovada quando o console exibiu o
resultado \texttt{[OK] [NVS TEST] Aprovado! Gravado=512, Lido=512}, indicando que
o valor recuperado corresponde ao valor armazenado.

No teste de SPIFFS, o sistema registra uma amostra de telemetria contendo dados
de sensores e valida a leitura posterior do conteúdo gravado. A execução foi
considerada aprovada quando o simulador exibiu
\texttt{[OK] [SPIFFS TEST] Aprovado! Telemetria gravada e validada localmente com
sucesso}. Além do teste local sem a placa física, o simulador permite uma etapa
opcional de integração com o \textit{backend} FastAPI: com a API em execução na
porta 8000, os dados persistidos podem ser sincronizados com o endpoint de
telemetria, validando o fluxo entre o armazenamento local simulado e o sistema
web.

\subsection{Atuadores}

Os motores DC foram testados individualmente utilizando o driver DRV8833. Os
ensaios contemplaram movimento para frente, movimento para trás, giro à
esquerda, giro à direita e parada controlada. Todos os comandos foram executados
pelos motores e registrados no monitor serial.

Após os testes básicos, foram implementadas rotinas de acionamento condicionadas
às leituras dos sensores, como interrupção do movimento ao detectar obstáculo e
correções de trajetória utilizando os encoders. O teste de odometria validou a
integração entre acionamento dos motores, contagem de pulsos e atualização da
orientação do robô. Nas evidências coletadas, o robô executa o avanço de uma
célula com deslocamento calculado de aproximadamente $0{,}208$ m, freia, gira
$90^\circ$ à direita, atualiza a orientação para Leste, gira $90^\circ$ à
esquerda e retorna à orientação Norte
(Figuras~\ref{fig:teste_odometria_1} e~\ref{fig:teste_odometria_2}).

Foi implementado controle PWM para ajuste da velocidade dos motores. Nos ensaios
registrados, foram avaliados duty cycles de 30\% e 60\%; os motores foram
acionados com comando de velocidade 60 para frente e, nos giros, com velocidades
opostas nos lados direito e esquerdo. Observou-se variação coerente da
movimentação em função dos comandos aplicados, indicando que o controle de
velocidade e sentido dos motores está operacional.

\subsection{Comunicações}

Foram realizados testes utilizando o barramento I\textsuperscript{2}C para
comunicação com sensores embarcados, incluindo o INA226. O dispositivo respondeu
corretamente aos comandos de leitura, permitindo a aquisição de tensão, corrente
e potência durante os ensaios de consumo.

A interface UART foi utilizada para depuração e monitoramento do sistema. Foram
transmitidas mensagens contendo estado do sistema, leituras dos sensores,
contagem de pulsos dos encoders, comandos de movimentação e informações de
diagnóstico. As evidências do Apêndice~\ref{apendice_evidencias_testes_hardware}
mostram o recebimento contínuo dessas mensagens durante os testes de odometria,
encoder e potência.

\section{Testes de consumo energético}
\subsection{Teste de consumo energético usando o INA226}
Para a validação do consumo energético real e do comportamento da fonte de alimentação escolhida, o robô foi testado com o sensor de potência INA226. O módulo comunicou-se com o microcontrolador ESP32, permitindo o registro em tempo real das variáveis de interesse durante a execução da rotina de movimentação.

A Tabela a seguir apresenta os dados empíricos coletados via terminal durante a fase de testes com os motores operando com esforço resistivo.

\begin{table}[hbt!]
    \centering
    \caption{Dados de Telemetria Aferidos via INA226 (Teste de Esforço)}
    \label{tab:dados_ina226_real}
    \vspace{0.2cm}
    \begin{tabular}{lccc}
        \hline
        \textbf{Estado de Operação} & \textbf{Tensão (V)} & \textbf{Corrente (mA)} & \textbf{Potência (W)} \\ 
        \hline
        Repouso (Standby) & 6,66 & 11,6 & 0,077 \\
        Movimentação (PWM 60) & 5,33 & 526,5 & 2,808 \\
        \hline
    \end{tabular}
    \par\vspace{0.2cm}
    Fonte: Elaborada pelos autores.
\end{table}

Os dados obtidos foram, surpreendentemente abaixo dos estimados teoricamente ($1050$ mA).

No estado de repouso (Standby), o sistema puxou $11,8$ mA. Durante o teste em vazio, a corrente subiu para $425,8$ mA, representação da energia necessária  para vencer a inércia e o atrito interno da caixa de redução dos motores.Ao ser colocado no solo (com esforço), a exigência de torque elevou a corrente para $526,5$ mA. Adicionalmente, observou-se o impacto da resistência interna das baterias: a tensão de barramento no teste físico sofreu uma queda considerada natural, passando de $6,61$ V em repouso para $5,33$ V sob carga máxima.Mesmo com essa variação, o barramento manteve-se acima dos níveis críticos de regulação, permitindo que o microcontrolador e os sensores continuassem funcionando sem falhas, concluindo a rotina com êxito.

\section{Testes de \textit{software}}
\label{sec:testes_software}

O \textit{backlog} do produto definido no primeiro ponto de controle (PC1) é composto por seis histórias
de usuário (HU01--HU06). Nesta entrega foram efetivamente implementadas e validadas
por testes automatizados as quatro histórias do módulo de \textit{software}
(web/\textit{backend}): HU03, HU04, HU05 e HU06, o que corresponde a $66{,}7\%$ do
\textit{backlog} funcional (acima do mínimo de $50\%$). As histórias HU01
(resolução autônoma) e HU02 (mapeamento incremental) pertencem ao módulo embarcado
e dependem da integração final com a placa ESP32, estando planejadas para a etapa
seguinte; por isso não compõem o conjunto validado nesta seção.

\begin{table}[H]
    \centering
    \caption{Associação entre histórias de usuário implementadas, protótipos e
    funcionalidades acessadas na interface gráfica.}
    \label{tab:hu_prototipo_gui}
    \footnotesize
    \begin{tabular}{|c|p{3.6cm}|c|p{3.6cm}|p{3.4cm}|}
        \hline
        \textbf{HU} & \textbf{História de usuário} & \textbf{Protótipo} &
        \textbf{Funcionalidade acessada na GUI} &
        \textbf{Suíte de testes que valida} \\ \hline

        HU03 & Telemetria em tempo real: trajeto, tempo, velocidade média e
        bateria durante a corrida. & Figura~\ref{fig:telemetria_fig} &
        Tela \textit{Telemetria ao Vivo}: grade do labirinto,
        métricas e status de conexão atualizados via WebSocket. &
        Unitário (\textit{Telemetry}, \textit{useTelemetry}); E2E
        \texttt{telemetria.spec.js}; \textit{backend} POST \texttt{/telemetria}
        e WS \texttt{/ws/telemetria}. \\ \hline

        HU04 & Persistência e consulta de histórico de corridas com filtro por
        tamanho. & Figura~\ref{fig:historicocorridas_fig} &
        Tela \textit{Histórico}: tabela de corridas
        e filtro por dimensão do labirinto. &
        Unitário (\textit{History}, \textit{useHistory}); E2E
        \texttt{history.spec.js}; \textit{backend} GET \texttt{/corridas}. \\ \hline

        HU05 & Monitoramento do nível de bateria no painel web. &
        Figura~\ref{fig:monitoramentobateria_fig} &
        Indicador de bateria na tela \textit{Telemetria ao Vivo}, alimentado pelo 
        campo \texttt{nivel\_bateria} da telemetria. &
        Coberta pelos testes de telemetria (unitário e E2E); validada com dados
        simulados. \\ \hline

        HU06 & Indicador de desafio cumprido (Sim/Não) ao atingir o centro do
        labirinto. & Figura~\ref{fig:desafiocumprido_fig} &
        Campo \textit{Desafio Cumprido} na tela \textit{Telemetria ao Vivo}, 
        calculado ao atingir a região central. &
        Unitário (\textit{Telemetry}); E2E \texttt{telemetria.spec.js}
        (casos ``Sim'' e ``Não''). \\ \hline
    \end{tabular}
\end{table}

A estratégia de testes do \textit{software} cobre três níveis: testes unitários e de
integração (de componentes e de rotas), com medição de cobertura de código-fonte, e
testes de sistema do tipo funcional (\textit{end-to-end}, E2E), que exercitam a
aplicação pela interface gráfica. Todas as suítes são executadas automaticamente a
cada \textit{push} ou \textit{pull request} por um \textit{pipeline} de Integração
Contínua (GitHub Actions), que reprova a alteração caso a cobertura fique abaixo de
$70\%$.

\subsection{Testes unitários e de integração}

No \textit{backend} (FastAPI), os testes foram escritos com \texttt{pytest} e
\texttt{pytest-cov}, empregando banco SQLite em memória e \textit{fixtures} que
substituem a sessão de banco real, de modo a não depender de infraestrutura externa.
No \textit{frontend} (React), foram utilizados \texttt{Vitest} e \textit{Testing
Library} sobre o ambiente \texttt{jsdom}. A Tabela~\ref{tab:suites_unit} resume as
suítes e a cobertura obtida, ambas acima do mínimo exigido de $70\%$; os relatórios
de cobertura correspondentes constam do Apêndice~\ref{apendice_evidencias_testes}
(Figuras~\ref{fig:cobertura_backend} e~\ref{fig:cobertura_frontend}).

\begin{table}[H]
    \centering
    \caption{Suítes de testes unitários e de integração e cobertura de código.}
    \label{tab:suites_unit}
    \small
    \begin{tabular}{|l|p{3.0cm}|p{5.2cm}|c|c|}
        \hline
        \textbf{Camada} & \textbf{Ferramentas} & \textbf{Principais suítes} &
        \textbf{Testes} & \textbf{Cobertura} \\ \hline
        \textit{Backend} & \texttt{pytest}, \texttt{pytest-cov} &
        telemetria (POST e WebSocket), encerramento de corrida (gatilho,
        agregados e transição de \textit{resultado}), \textit{models} e
        \textit{schemas}, histórico/consulta e \textit{health} & 83 & $98\%$ \\ \hline
        \textit{Frontend} & \texttt{Vitest}, \textit{Testing Library} &
        páginas \textit{Telemetry} e \textit{History}, componentes \textit{Layout} e
        \textit{MazeMap}, \textit{hooks} e roteamento & 37 & $93\%$ \\ \hline
    \end{tabular}
\end{table}

\subsection{Testes de sistema (E2E)}

Os testes de sistema foram automatizados com \texttt{Playwright}, executados em modo
\textit{headless} (compatível com a Integração Contínua). As suítes automatizam os
casos funcionais de \textit{software} do roteiro de testes
(Apêndice~\ref{apendice_roteiro_detalhado}); os casos do módulo embarcado (TF01 e
TF02) dependem da integração com a ESP32 e serão validados posteriormente. A suíte
completa soma 19 casos. As suítes que exercitam o fluxo de telemetria, por validarem
a integração entre os módulos, são detalhadas na Seção~\ref{sec:testes_integracao};
as suítes funcionais da aplicação web (consulta de histórico e navegação) constam da
Tabela~\ref{tab:suites_e2e}.

\begin{table}[H]
    \centering
    \caption{Suítes de testes de sistema (E2E) automatizadas com Playwright.}
    \label{tab:suites_e2e}
    \small
    \begin{tabular}{|l|p{9.3cm}|}
        \hline
        \textbf{Suíte} & \textbf{Cenários validados} \\ \hline
        \texttt{history.spec.js} & Consulta do histórico e filtro por tamanho de
        labirinto, incluindo a restauração da listagem completa (4 casos). \\ \hline
        \texttt{smoke.spec.js} & Carregamento básico da aplicação e navegação inicial
        entre as telas (2 casos). \\ \hline
    \end{tabular}
\end{table}

A execução das suítes, a verificação do limiar de cobertura e a coleta das evidências
(relatórios de cobertura e do Playwright) são realizadas automaticamente pelo
\textit{pipeline} de Integração Contínua, garantindo que a \textit{branch} principal
permaneça sempre com os testes verdes. O relatório de execução dos testes E2E é
apresentado na Figura~\ref{fig:e2e_playwright} (Apêndice~\ref{apendice_evidencias_testes}).

\section{Testes de integração}
\label{sec:testes_integracao}

A integração da comunicação de telemetria foi validada entre os componentes de
\textit{software} (API, persistência, WebSocket e \textit{frontend}), com a fonte de
dados simulada por um dublê de WebSocket e um cliente de teste que reproduzem o
contrato \texttt{TelemetriaOut}. A integração com o \textit{firmware} real da ESP32 está
planejada para a \textit{sprint}-5 (\#22 e \#23).

O fluxo de telemetria é o principal ponto de integração do sistema, pois atravessa
todas as camadas do \textit{software}: o sistema embarcado, a API, o banco de dados, o
canal de tempo real e a interface web. Por isso, esta seção concentra a verificação
desse caminho de ponta a ponta. O fluxo é o seguinte: um emissor de telemetria (um
simulador em \textit{Python} que mimetiza o \textit{firmware}, ou um dublê de WebSocket
executado no navegador) envia pacotes ao \textit{endpoint} \texttt{POST /telemetria}; o
\textit{backend} valida o pacote, persiste o evento, resolve a corrida associada
(criando-a no primeiro pacote e reutilizando-a nos seguintes) e repassa o dado, em
tempo real, a todos os clientes conectados pelo canal \texttt{/ws/telemetria}; por fim,
a interface web recebe o evento e atualiza o painel. Esse fluxo corresponde ao diagrama
de sequência da corrida completa apresentado na Figura~\ref{fig:diagrama_sequencia}.

A verificação cobre as quatro etapas desse contrato, da ingestão do pacote até o
consumo pela interface, combinando testes de integração de \textit{backend} (que
exercitam diretamente a API, a persistência e o \textit{broadcast}) com testes de
sistema fim a fim. Ao todo, treze casos automatizados de E2E (doze do fluxo ao vivo e um
de robustez de reconexão) somam-se aos testes de integração de \textit{backend} para
cobrir o caminho completo da telemetria. A Tabela~\ref{tab:testes_integracao} detalha
cada teste, os componentes que ele integra e os cenários validados.
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

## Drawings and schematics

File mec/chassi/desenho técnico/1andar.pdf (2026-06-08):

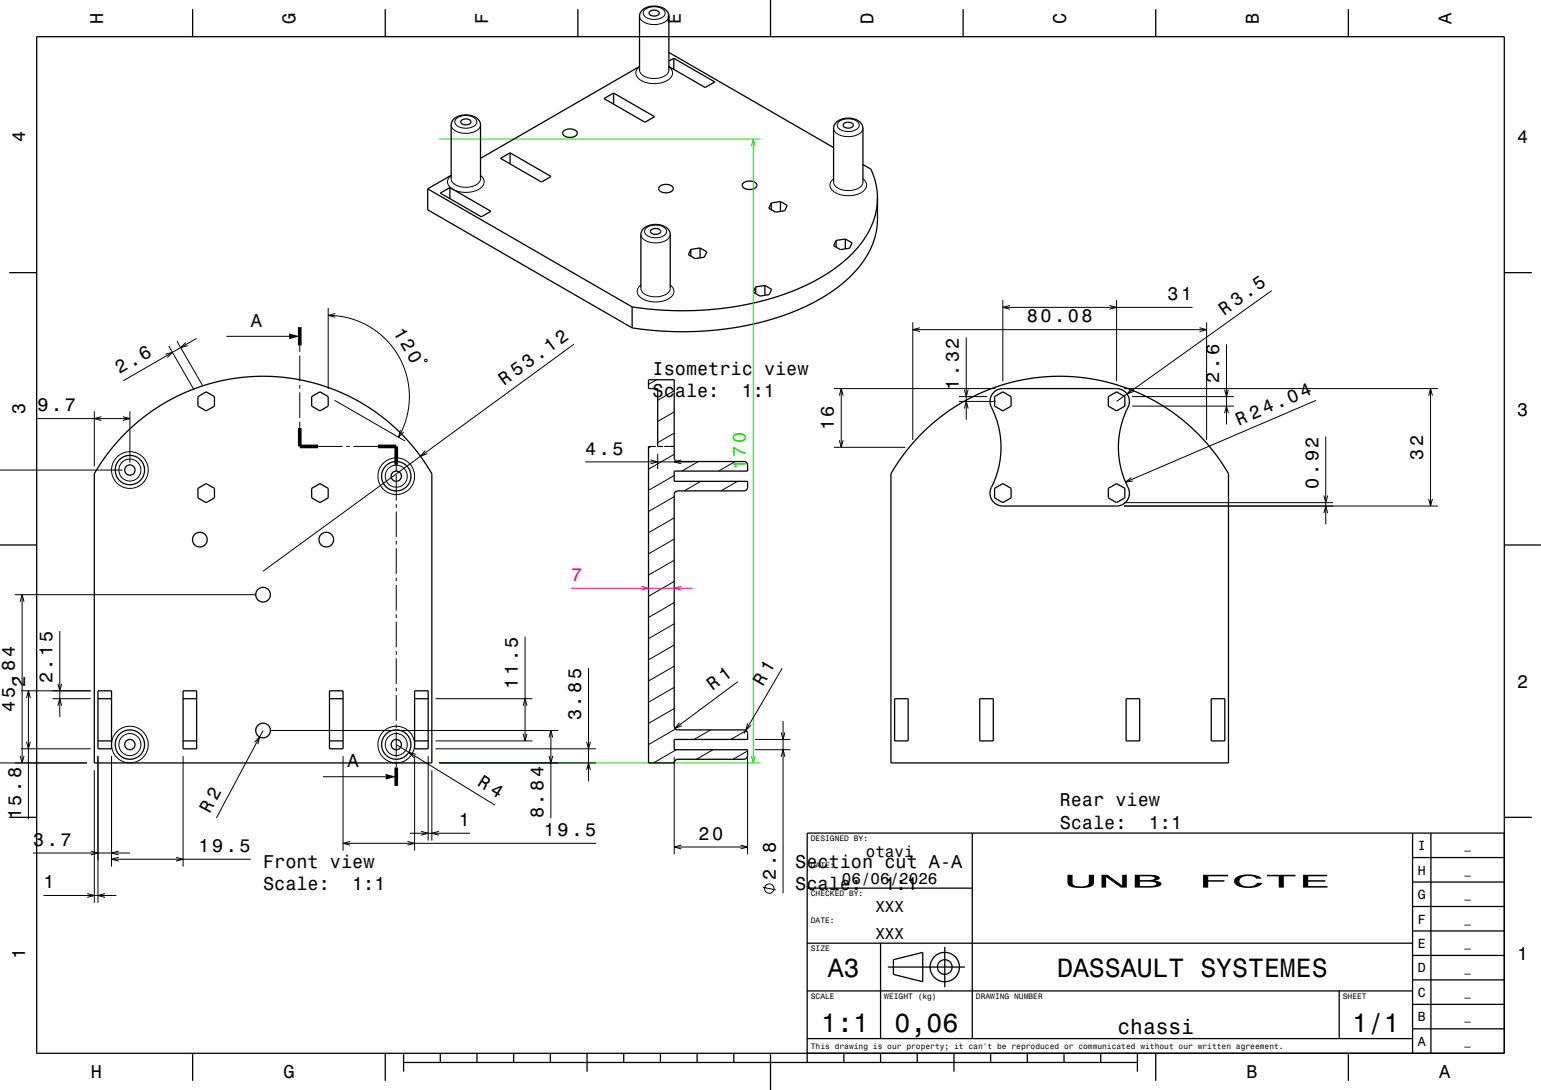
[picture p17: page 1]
CHECKED BY:; DESIGNED BY:; Front view Scale: 1:1; Rear view Scale: 1:1; Scale: 1:1; Section cut A-A Scale: 1:1

SIZE A3 | | | | DASSAULT SYSTEMES

SCALE 1:1 | WEIGHT (kg) 0,06 | DRAWING NUMBER chassi | SHEET 1/1

This drawing is our property; it can't be reproduced or communicated without our written agreement.

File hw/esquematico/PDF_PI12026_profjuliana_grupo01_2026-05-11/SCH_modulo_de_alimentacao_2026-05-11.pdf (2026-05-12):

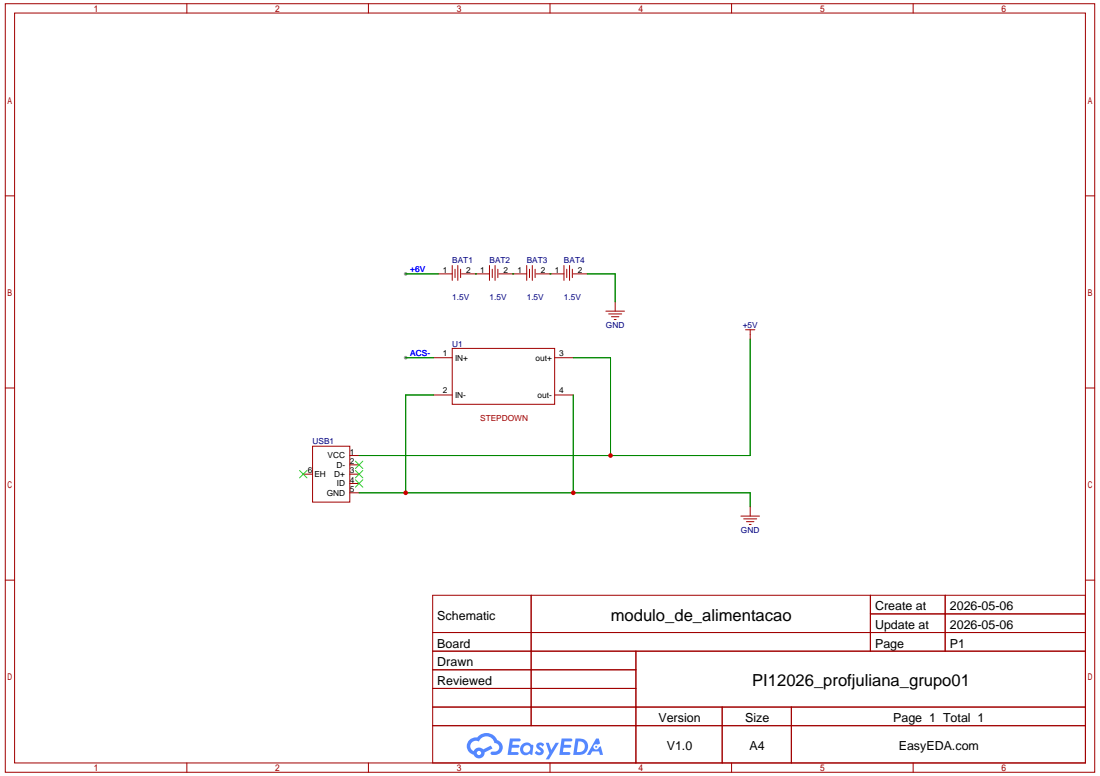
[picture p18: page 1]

Schematic | modulo_de_alimentacao | Create at | 2026-05-06

Update at | 2026-05-06

Board | | Page | P1
Drawn | | PI12026_profjuliana_grupo01
Reviewed

Version | Size | Page 1 Total 1
V1.0 | A4 | EasyEDA.com

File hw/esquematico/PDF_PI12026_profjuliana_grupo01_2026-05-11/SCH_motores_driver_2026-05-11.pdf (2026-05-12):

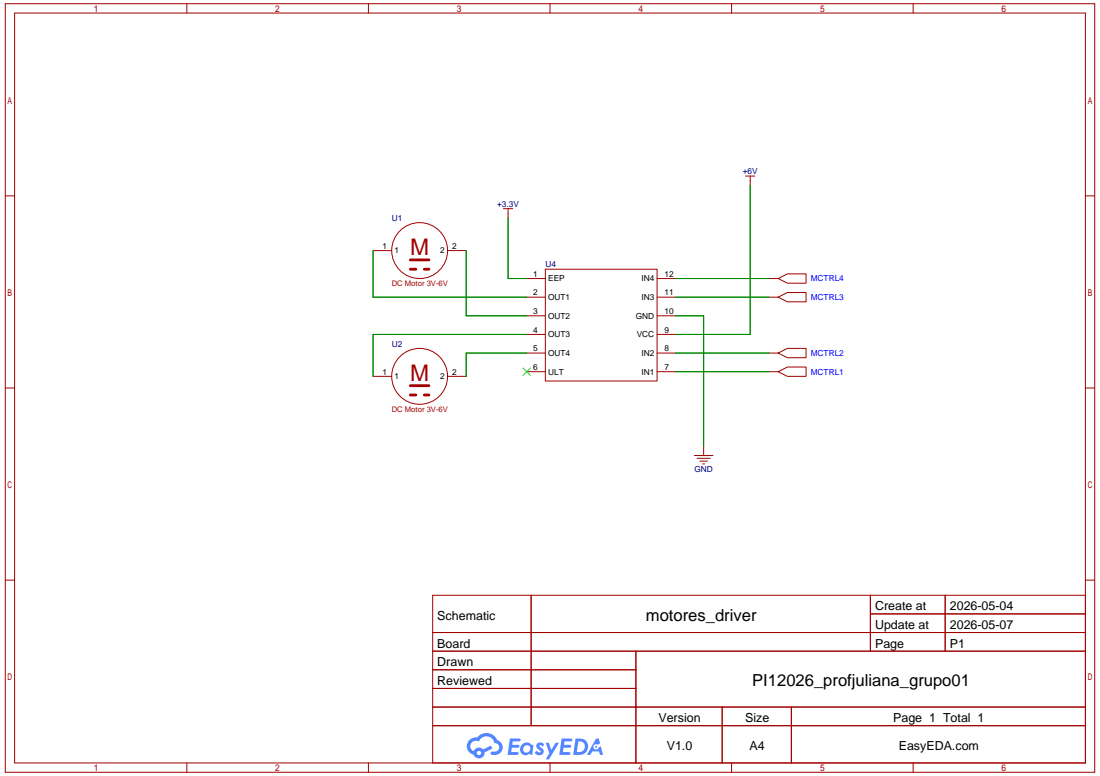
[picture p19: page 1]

Schematic | motores_driver | Create at | 2026-05-04

Update at | 2026-05-07

Board | | Page | P1
Drawn | | PI12026_profjuliana_grupo01
Reviewed

Version | Size | Page 1 Total 1
V1.0 | A4 | EasyEDA.com

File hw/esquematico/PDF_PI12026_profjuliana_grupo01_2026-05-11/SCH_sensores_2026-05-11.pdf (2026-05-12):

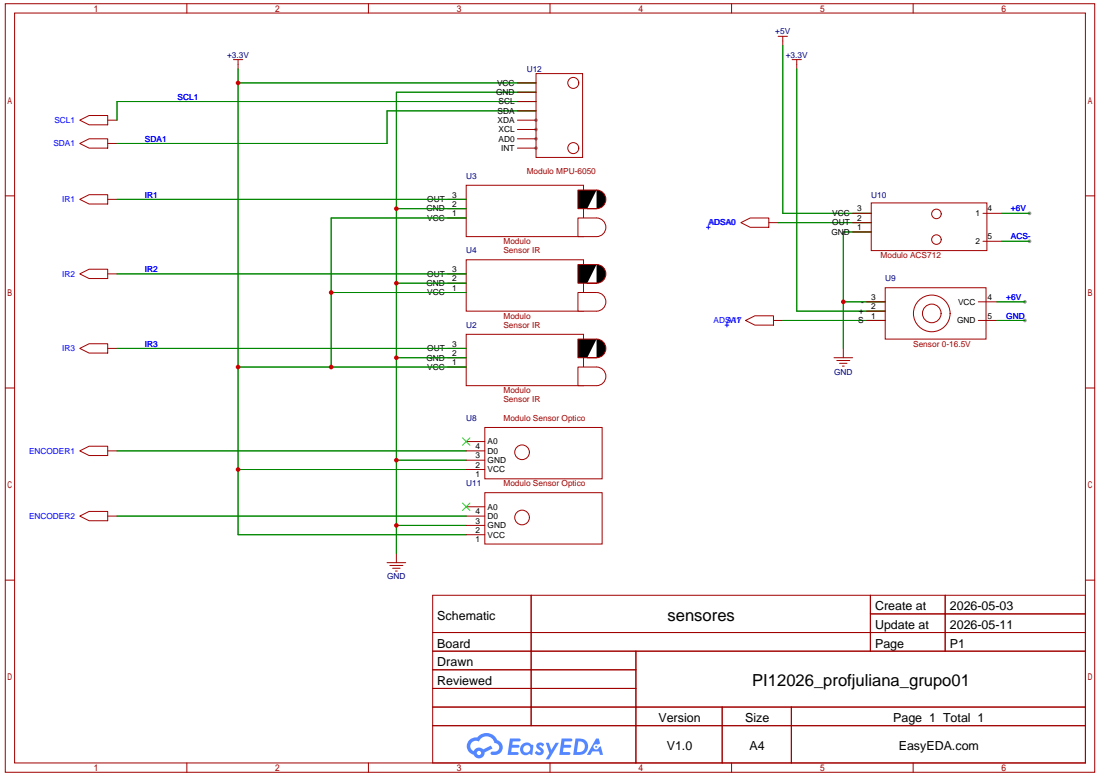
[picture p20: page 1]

Schematic | sensores | Create at | 2026-05-03

Update at | 2026-05-11

Board | | Page | P1
Drawn | | PI12026_profjuliana_grupo01
Reviewed

Version | Size | Page 1 Total 1
V1.0 | A4 | EasyEDA.com

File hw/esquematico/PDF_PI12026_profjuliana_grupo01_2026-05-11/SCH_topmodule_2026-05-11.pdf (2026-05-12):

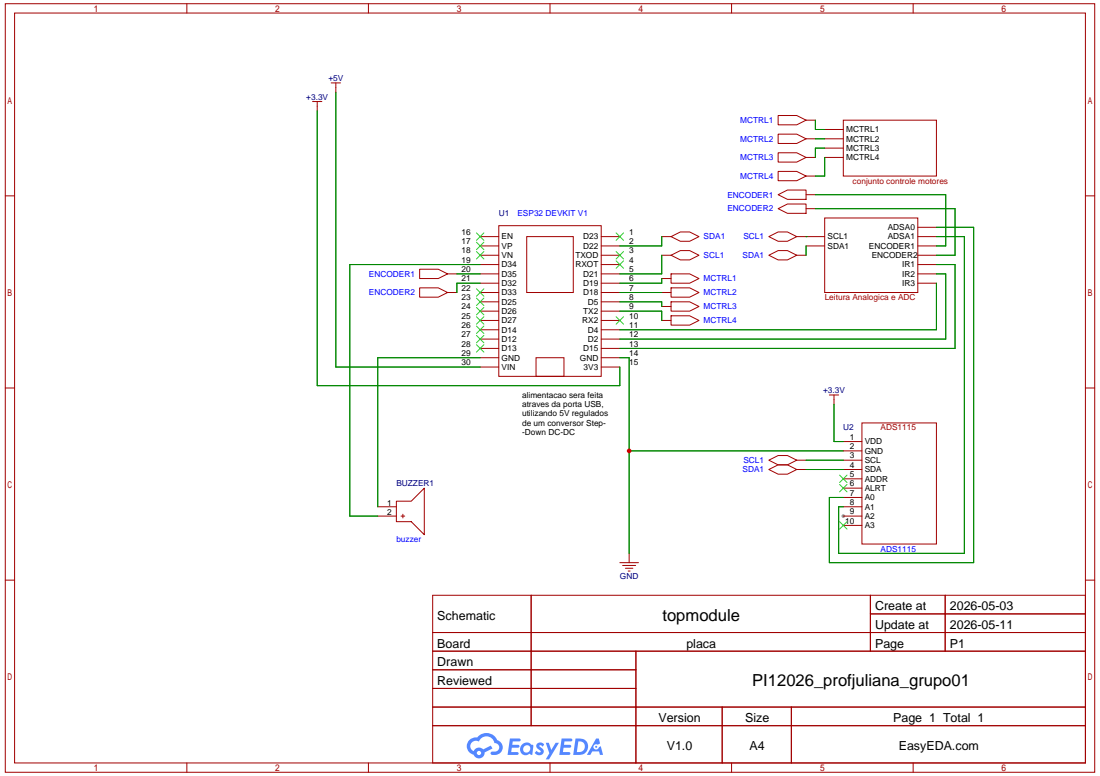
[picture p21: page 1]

alimentacao sera feita
atraves da porta USB,
utilizando 5V regulados
de um conversor Step-
-Down DC-DC

Schematic | topmodule | Create at | 2026-05-03

Update at | 2026-05-11

Board | placa | Page | P1
Drawn | | PI12026_profjuliana_grupo01
Reviewed

Version | Size | Page 1 Total 1
V1.0 | A4 | EasyEDA.com


Schematic | motores_driver | Create at | 2026-05-04

Update at | 2026-05-07

Board | | Page | P1
Drawn | | PI12026_profjuliana_grupo01
Reviewed


Schematic | sensores | Create at | 2026-05-03

Update at | 2026-05-11

Board | | Page | P1
Drawn | | PI12026_profjuliana_grupo01
Reviewed

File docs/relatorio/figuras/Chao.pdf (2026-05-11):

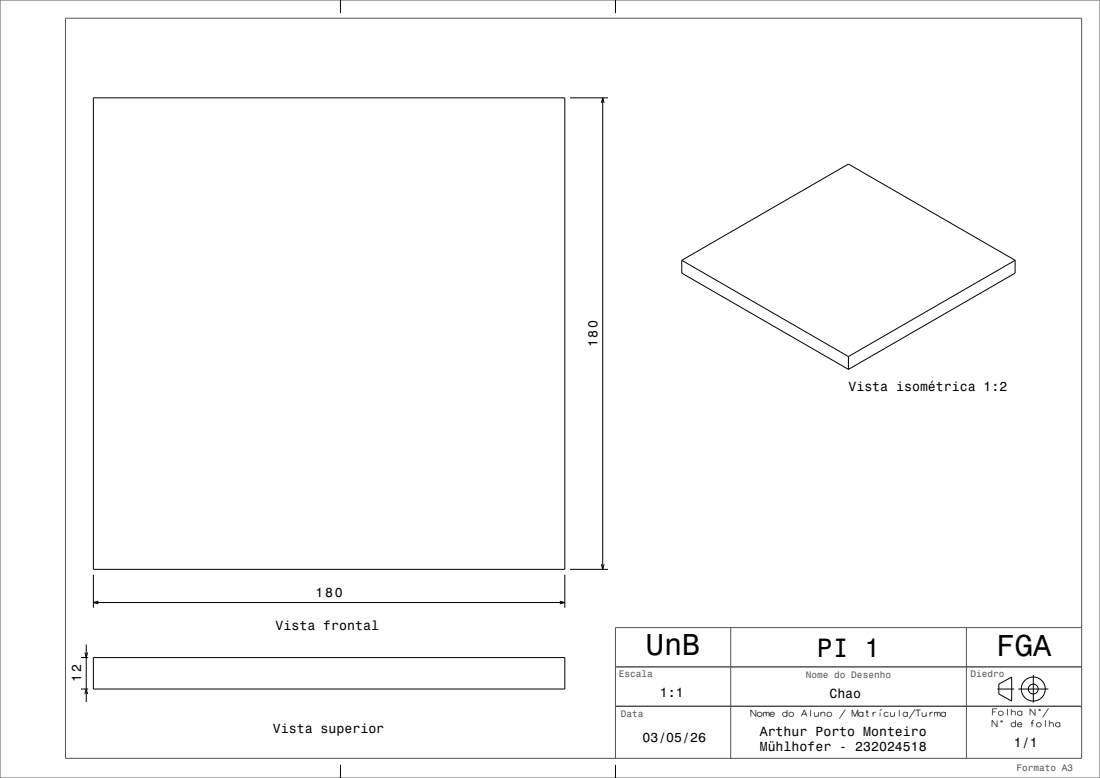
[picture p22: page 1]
Formato A3; Vista frontal; Vista superior; Vista isométrica 1:2

UnB | PI 1 | FGA

Escala 1:1 | Nome do Desenho Chao | Diedro

Data 03/05/26 | Arthur Porto Monteiro Mühlhofer - 232024518 | 1/1

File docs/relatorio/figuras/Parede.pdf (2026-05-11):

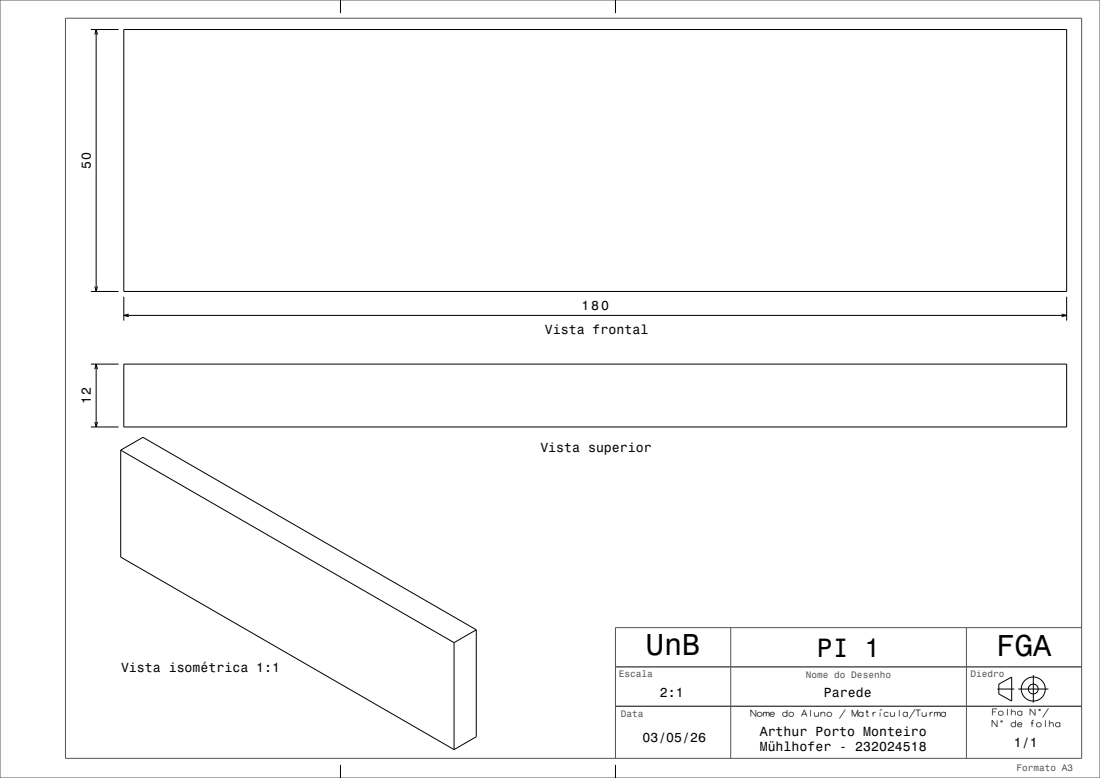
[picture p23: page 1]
Formato A3; Vista frontal; Vista superior; Vista isométrica 1:1

UnB | PI 1 | FGA

Escala 2:1 | Nome do Desenho Parede | Diedro

Data 03/05/26 | Arthur Porto Monteiro Mühlhofer - 232024518 | 1/1

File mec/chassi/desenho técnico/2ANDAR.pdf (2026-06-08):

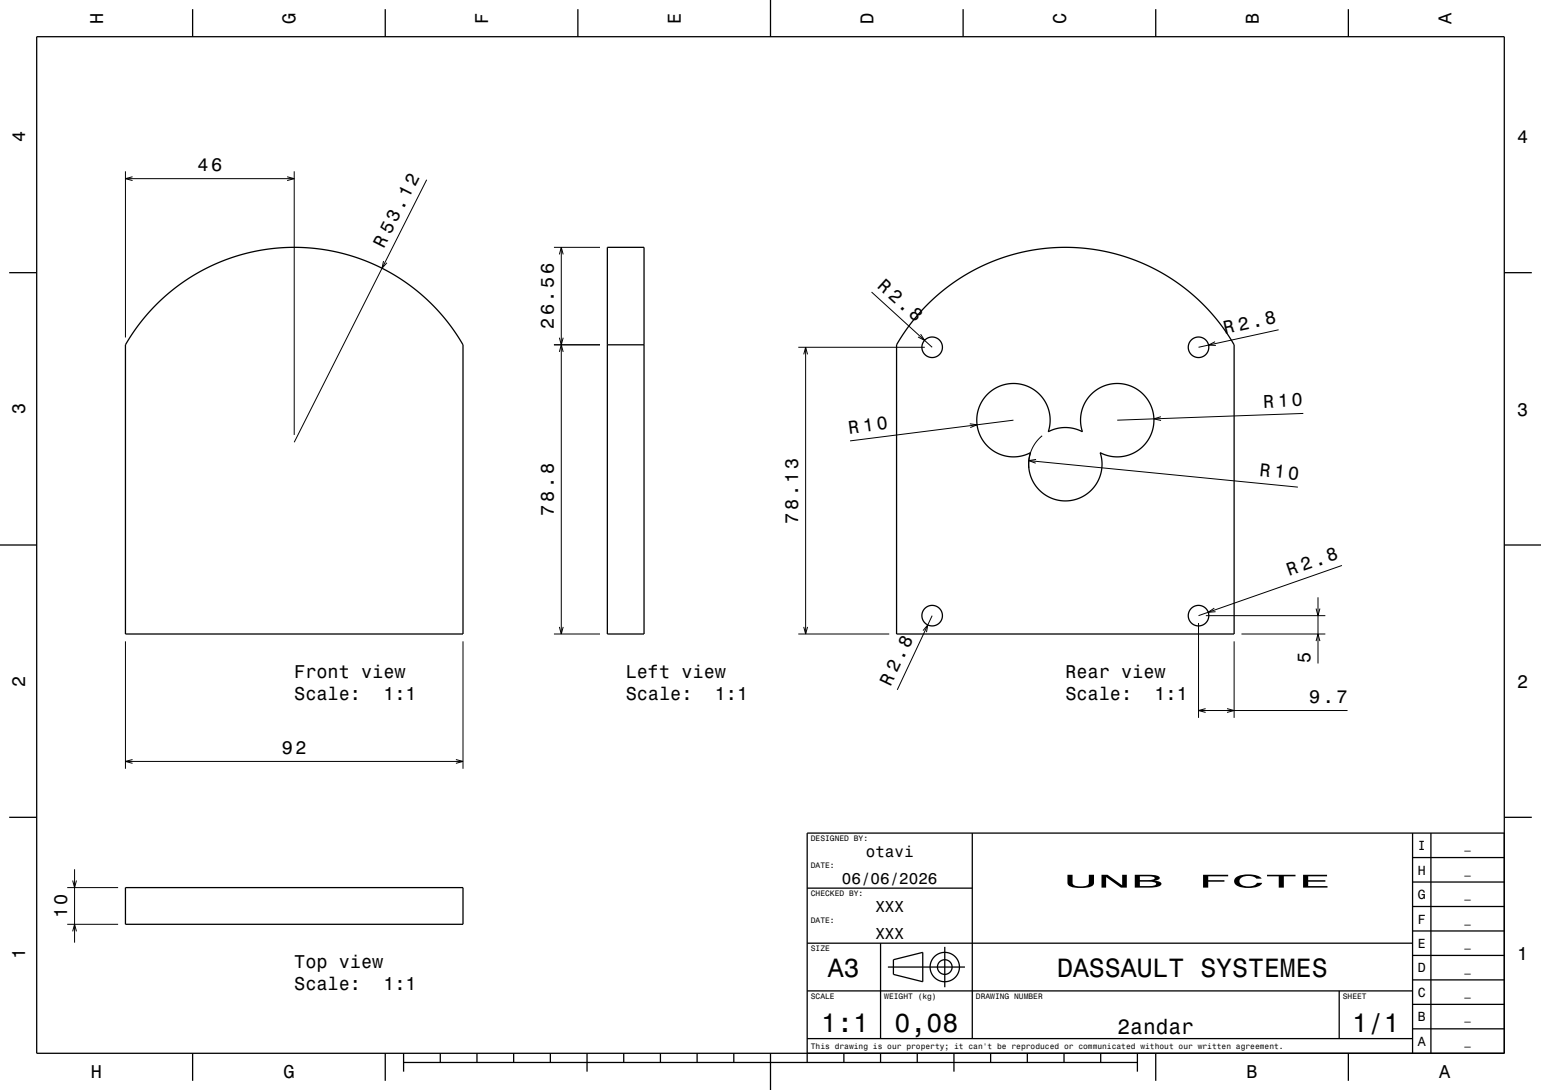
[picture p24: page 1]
CHECKED BY:; Front view Scale: 1:1; Rear view Scale: 1:1; Top view Scale: 1:1; Left view Scale: 1:1

DESIGNED BY: otavi DATE: 06/06/2026 | UNB FCTE | I | _

SIZE A3 | | | | DASSAULT SYSTEMES

SCALE 1:1 | WEIGHT (kg) 0,08 | DRAWING NUMBER 2andar | SHEET 1/1

This drawing is our property; it can't be reproduced or communicated without our written agreement.

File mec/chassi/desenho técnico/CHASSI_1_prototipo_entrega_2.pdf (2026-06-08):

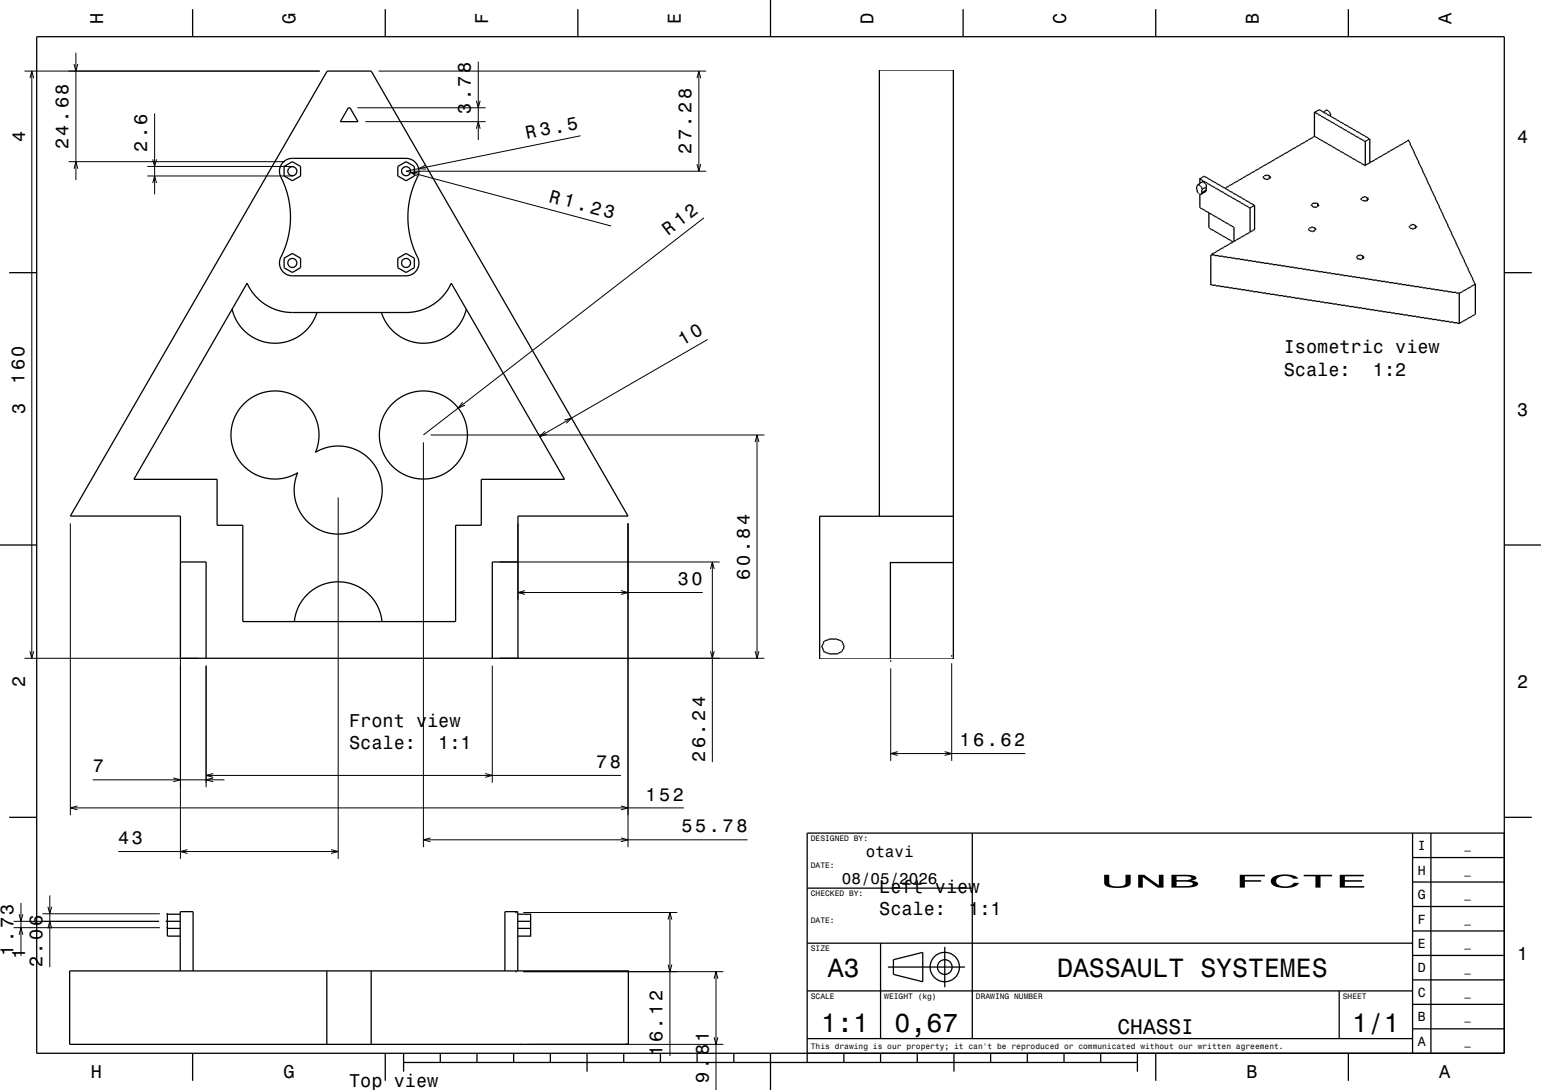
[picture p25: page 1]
CHECKED BY:; Isometric view Scale: 1:2; Front view; Scale: 1:1

DESIGNED BY: otavi DATE: 08/05/2026 Left view | UNB FCTE | I | _

SIZE A3 | | | | DASSAULT SYSTEMES

SCALE 1:1 | WEIGHT (kg) 0,67 | DRAWING NUMBER CHASSI | SHEET 1/1

This drawing is our property; it can't be reproduced or communicated without our written agreement.

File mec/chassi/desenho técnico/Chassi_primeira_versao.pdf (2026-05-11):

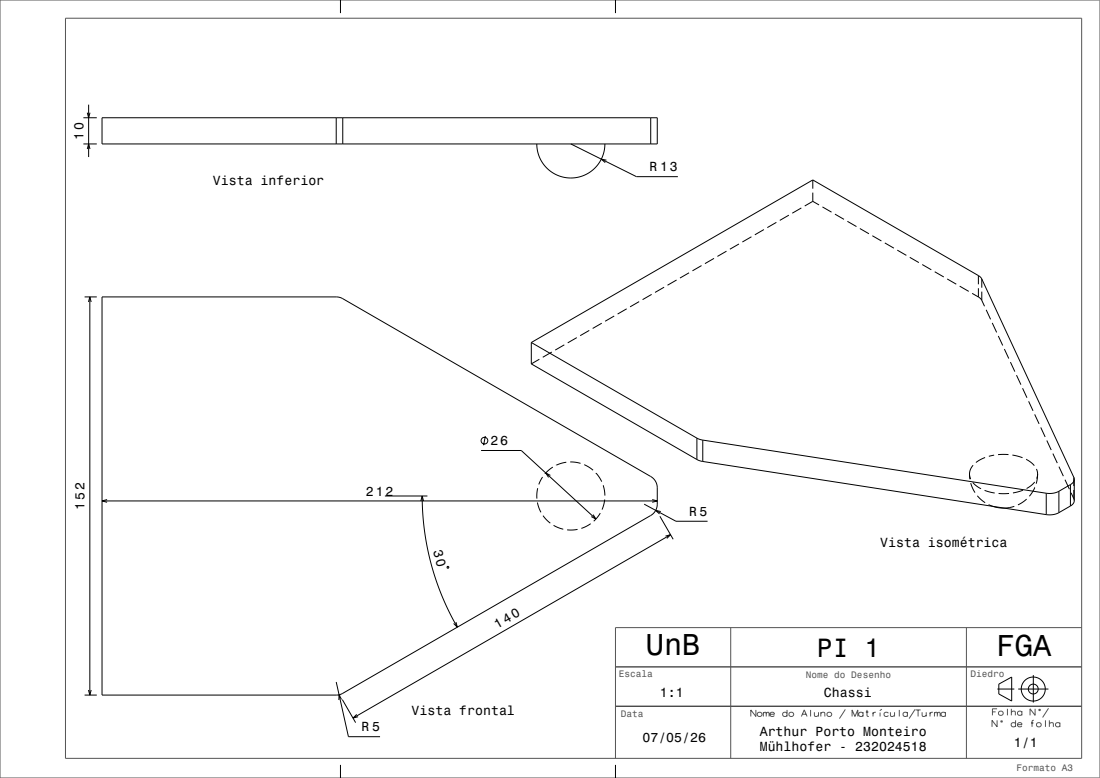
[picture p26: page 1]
Formato A3; Vista frontal; Vista inferior; Vista isométrica

UnB | PI 1 | FGA

Escala 1:1 | Nome do Desenho Chassi | Diedro

Data 07/05/26 | Arthur Porto Monteiro Mühlhofer - 232024518 | 1/1

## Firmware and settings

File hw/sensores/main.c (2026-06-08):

#include <stdio.h>
#include "freertos/FreeRTOS.h"
#include "freertos/task.h"
#include "driver/gpio.h"

#define SENSOR_1 GPIO_NUM_12
#define SENSOR_2 GPIO_NUM_15
#define SENSOR_3 GPIO_NUM_13

void app_main(void)
{
    gpio_config_t io_conf = {};

    io_conf.mode = GPIO_MODE_INPUT;

    io_conf.pin_bit_mask =
        (1ULL << SENSOR_1) |
        (1ULL << SENSOR_2) |
        (1ULL << SENSOR_3);

    io_conf.pull_up_en = GPIO_PULLUP_DISABLE;
    io_conf.pull_down_en = GPIO_PULLDOWN_DISABLE;

    gpio_config(&io_conf);

    while (1)
    {
        int s1 = gpio_get_level(SENSOR_1);
        int s2 = gpio_get_level(SENSOR_2);
        int s3 = gpio_get_level(SENSOR_3);

        printf("S1:%d | S2:%d | S3:%d\n", s1, s2, s3);

        vTaskDelay(pdMS_TO_TICKS(500));
    }
}

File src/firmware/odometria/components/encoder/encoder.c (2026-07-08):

//codigo-fonte leitura dos encoders acoplados aos motores
//abaixo estao declaradas as bibliotecas necessarias

#include <stdio.h>
#include <math.h>

#include "driver/gpio.h"
#include "driver/pulse_cnt.h"
#include "esp_err.h"
#include "esp_log.h"

#include "encoder.h"

static const char *TAG = "encoder";

//rotina de configuracoes iniciais do periferico pcnt
esp_err_t encoder_init(encoder_t *encoder, gpio_num_t gpio)
{
    if (encoder == NULL)
    {
        return ESP_ERR_INVALID_ARG;
    }

    encoder->gpio = gpio;

    pcnt_unit_config_t unit_config = {
        .high_limit = 32767,
        .low_limit = -32768,
    };

    ESP_ERROR_CHECK(
        pcnt_new_unit(
            &unit_config,
            &(encoder->unit)
        )
    );

    pcnt_chan_config_t chan_config = {
        .edge_gpio_num = gpio,
        .level_gpio_num = -1,
    };

    ESP_ERROR_CHECK(
        pcnt_new_channel(
            encoder->unit,
            &chan_config,
            &(encoder->channel)
        )
    );

    ESP_ERROR_CHECK(
        pcnt_channel_set_edge_action(
            encoder->channel,
            PCNT_CHANNEL_EDGE_ACTION_INCREASE,
            PCNT_CHANNEL_EDGE_ACTION_HOLD
        )
    );

    pcnt_glitch_filter_config_t filter_config = {
        .max_glitch_ns = 1000,
    };

    ESP_ERROR_CHECK(
        pcnt_unit_set_glitch_filter(
            encoder->unit,
            &filter_config
        )
    );

    ESP_ERROR_CHECK(
        pcnt_unit_enable(
            encoder->unit
        )
    );

    ESP_ERROR_CHECK(
        pcnt_unit_clear_count(
            encoder->unit
        )
    );

    ESP_ERROR_CHECK(
        pcnt_unit_start(
            encoder->unit
        )
    );

    ESP_LOGI(TAG, "encoder: iniciado"); 
    return ESP_OK;
}

void encoder_clean(encoder_t *encoder){

    pcnt_unit_clear_count(encoder->unit);
    
    ESP_LOGI(TAG, "encoder resetado");
}

static int encoder_consume_count(encoder_t *encoder)
{
    int count = 0;

    pcnt_unit_get_count(encoder->unit, &count);
    pcnt_unit_clear_count(encoder->unit);

    ESP_LOGD(TAG, "pulsos lidos: %d", count);
    return count;
}

//movimento estimado do eixo do motor [rad]
//baseado na condicao de que a leitura e feita
//com o carrinho parado...
float encoder_get_teta(encoder_t *encoder){
    int pulsos = encoder_consume_count(encoder);
    return (pulsos * M_PI) / 10.0f;
}

//velocidade angular media [rad/s]
float encoder_get_w(encoder_t *encoder, float dt){
    
    float dteta = encoder_get_teta(encoder);

    float w = dteta/dt;

    return w;
}

//velocidade linear media [m/s]
float encoder_get_v(encoder_t *encoder, float dt, float raio){
    float w = encoder_get_w(encoder, dt);
    float v = w * raio;

    return v;
}

//deslocamento estimado [m]
float encoder_get_deslocamento(encoder_t *encoder, float raio, int *pulsos_lidos){

    int pulsos = encoder_consume_count(encoder);
    if (pulsos_lidos != NULL) {
        *pulsos_lidos = pulsos;
    }

    float teta = (pulsos * M_PI) / 10.0f;
    return teta * raio;
}

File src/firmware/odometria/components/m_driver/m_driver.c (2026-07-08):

//codigo-fonte driver de motores com drv8833 no modo pwm
//abaixo estao declaradas as bibliotecas necessarias
#include "m_driver.h"

#include "driver/mcpwm_prelude.h"
#include "esp_log.h"
#include "driver/gpio.h"

static const char *TAG = "motor";

//timer
static mcpwm_timer_handle_t timer = NULL;
static mcpwm_oper_handle_t oper1 = NULL;
static mcpwm_oper_handle_t oper2 = NULL;

//rotina de configuracoes iniciais para timer, operador e gpio
void driver_init(){
    //configuracao da frequencia do timer pwm
    //para este projeto, estaremos usando 20kHz

    //(freq = resolution_hz/period_ticks)

    mcpwm_timer_config_t timer_config = {
        .group_id = 0,
        .clk_src = MCPWM_TIMER_CLK_SRC_DEFAULT,
        .resolution_hz = HZ_RES,
        .period_ticks = PERIOD_TICKS,
        .count_mode = MCPWM_TIMER_COUNT_MODE_UP
    };

    mcpwm_new_timer(
        &timer_config,
        &timer
    );

    //configurando o pino de saida para freio
    gpio_config_t io_conf = {
    .pin_bit_mask = (1ULL << SEL),
    .mode = GPIO_MODE_OUTPUT,
    .pull_up_en = GPIO_PULLUP_DISABLE,
    .pull_down_en = GPIO_PULLDOWN_DISABLE,
    .intr_type = GPIO_INTR_DISABLE
    };

    gpio_config(&io_conf);
    
    //configurando os operadores
    mcpwm_operator_config_t operator_config = {
        .group_id = 0
    };

    mcpwm_new_operator(
        &operator_config,
        &oper1
    );

    mcpwm_new_operator(
        &operator_config,
        &oper2
    );


    mcpwm_operator_connect_timer(
        oper1,
        timer
    );
    mcpwm_operator_connect_timer(
        oper2,
        timer
    );

    //inicia timer
    mcpwm_timer_enable(timer);

    mcpwm_timer_start_stop(
        timer,
        MCPWM_TIMER_START_NO_STOP
    );
}

//declaracoes necessarias para operacao do periferico "MCPWM" (motor control pulse width modulation) da ESP32
void motor_init(motor_t *motor){

    //configurando e criando os comparadores
    mcpwm_comparator_config_t cmp_config = {
        .flags.update_cmp_on_tez = true
    };
	//comparador1
    mcpwm_new_comparator(
        oper1,
        &cmp_config,
        &motor->comp1
    );
	//comparador2
    mcpwm_new_comparator(
        oper2,
        &cmp_config,
        &motor->comp2
    );
    
    //configurando os geradores
    mcpwm_generator_config_t gen_config = { .gen_gpio_num = motor->pwm_gpio1 };

    mcpwm_new_generator(
        oper1,
        &gen_config,
        &motor->gen1
    );
	//gerador2
    gen_config.gen_gpio_num = motor->pwm_gpio2;
    mcpwm_new_generator(
        oper2,
        &gen_config,
        &motor->gen2
    );

    //configurando PWM
    mcpwm_generator_set_action_on_timer_event(
        motor->gen1,
        MCPWM_GEN_TIMER_EVENT_ACTION(
            MCPWM_TIMER_DIRECTION_UP,
            MCPWM_TIMER_EVENT_EMPTY,
            MCPWM_GEN_ACTION_HIGH
        )
    );

    mcpwm_generator_set_action_on_compare_event(
        motor->gen1,
        MCPWM_GEN_COMPARE_EVENT_ACTION(
            MCPWM_TIMER_DIRECTION_UP,
            motor->comp1,
            MCPWM_GEN_ACTION_LOW
        )
    );

    mcpwm_generator_set_action_on_timer_event(
        motor->gen2,
        MCPWM_GEN_TIMER_EVENT_ACTION(
            MCPWM_TIMER_DIRECTION_UP,
            MCPWM_TIMER_EVENT_EMPTY,
            MCPWM_GEN_ACTION_HIGH
        )
    );

    mcpwm_generator_set_action_on_compare_event(
        motor->gen2,
        MCPWM_GEN_COMPARE_EVENT_ACTION(
            MCPWM_TIMER_DIRECTION_UP,
            motor->comp2,
            MCPWM_GEN_ACTION_LOW
        )
    );

    ESP_LOGI(TAG, "INICIANDO MOTOR DESLIGADO");
    //iniciar motor desligado
    motor_set_speed(motor, 0);
}

//funcoes para controle de velocidade
static void set_pwm(
    mcpwm_cmpr_handle_t cmp,
    uint8_t duty
)
{
    uint32_t ticks =
        (PERIOD_TICKS * duty) / 100;

    mcpwm_comparator_set_compare_value(
        cmp,
        ticks
    );
}

void motor_set_speed(motor_t *motor, int8_t speed){
    ESP_LOGD(TAG, "velocidade do motor: %d", speed);
        if(speed >= 25 && speed <= 100)
    {
        set_pwm(motor->comp1, speed);
	set_pwm(motor->comp2, 0);
    }
    else if(speed <= -25 && speed >= -100)
    {
	set_pwm(motor->comp1, 0);
        set_pwm(motor->comp2, -speed);
    }
    else
    {
        set_pwm(motor->comp1, 0);
        set_pwm(motor->comp2, 0);
    }
}

void motor_stop(motor_t *motor){
        set_pwm(motor->comp1, 0);
        set_pwm(motor->comp2, 0);
}

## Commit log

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2026-05-08 fix: correcao do relatorio para ficar de acordo com a issue (#2)
2026-05-08 fix: tirando topicos que nao entram no escopo (#2)
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2026-05-08 fix: Centraliza tabelas do capítulo de análise de consumo energético
    Adiciona resizebox para que as tabelas caibam na largura da página
2026-05-08 fix: Centraliza tabela de cronograma do subgrupo de energia
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2026-05-09 docs(database): adiciona instrucoes de execucao ao schema (#12)
    Add detailed database schema documentation for Micromouse telemetry system, including entities, attributes, and structure.
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2026-05-09 docs: adicao de exmplicacao sobre o diagrama de caso de uso (#10)
2026-05-09 fix: Padroniza tabela de cronograma do subgrupo de energia
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2026-05-10 feat: adiciona nova atividade "Criar Cronograma" ao cronograma do subgrupo de hardware
2026-05-10 feat: adiciona nova atividade "Justificar componentes" ao cronograma do subgrupo de hardware
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2026-05-10 feat: add CAD files for Chao, Parede, Pista, and Teto
    [Chao.CATPart, Parede.CATPart, Pista.CATProduct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]
2026-05-10 feat: add new CAD files for Chassi, Conversor, Driver Motor, ESP32, Motor, Part8, Protoboard, Roda, Sensor IR, and StepDown
    [Chassi.CATPart, Conversor.CATPart, Driver Motor.CATPart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]
2026-05-10 docs: adição do restante das justificativas da escolha dos componentes de hardware
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2026-05-11 feat: atualiza as dimensões do CAD e revisa as decisões de modularidade do projeto
2026-05-11 feat: detalha o projeto estrutural do micromouse e do labirinto de testes
2026-05-11 fix(docs): corrige navegação da lista de tabelas e layout da capa
    - 08_cronograma.tex: troca [htpb] por [H] nas tabelas para fixá-las no
    local correto, evitando que flutuem e quebrem os links da lista de
    tabelas. Adiciona labels faltantes.
    - customizacoes.sty: reorganiza espaçamentos da capa para que os 19
    nomes dos autores não invadam a área verde inferior e para que a
    data volte a ser renderizada.
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2026-05-11 docs: adiciona roteiro de testes funcionais (TF01–TF08)
    Substitui o placeholder vermelho do Roteiro de testes funcionais por uma
    longtable em paisagem com as seis colunas exigidas (Código, Nome,
    Objetivo, Pré-condições, Procedimento e Resultado esperado) cobrindo
    HU01–HU06 e rastreando RF e UC correspondentes.
    Closes #2
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2026-05-13 docs: corrige campo de placeholder na descrição da atividade
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2026-06-01 test(backend): adiciona fixtures de teste com banco isolado
    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
2026-06-01 chore(frontend): adiciona Vitest e Testing Library e scripts de teste
    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
2026-06-02 test(frontend): restringe Vitest a src para coexistir com os e2e
    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
2026-06-02 feat(web): implementa tela de telemetria ao vivo (#19)
    - consome o WebSocket /ws/telemetria como observador passivo (hook useTelemetry)
    - grid NxN (4x4/8x8/16x16) com trajeto, posicao atual e celula de chegada
    - painel de bateria, velocidade media, tempo e indicador de desafio cumprido
    - status de conexao com reconexao automatica
    - teste de unidade da pagina com WebSocket mockado
2026-06-02 test(web): adiciona e2e de robustez de reconexão (#132)
    Simula a queda do WebSocket via socket falso injetado no navegador e valida
    o indicador de conexao perdida, a reconexao automatica e a retomada da
    atualizacao dos dados. Automatiza o roteiro manual da issue #24.
2026-06-02 test(web): adapta MazeMap.test.jsx ao novo componente de telemetria
    O #140 reescreve o MazeMap (legenda, role=grid e mensagem de telemetria),
    quebrando os testes da T12 (#129) que ja estao na main. Usa getByRole('grid')
    no lugar do seletor por estrutura de DOM e atualiza o texto esperado.
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2026-06-02 feat(historico): implementa tela de histórico com filtro e tabela de corridas (#20)
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2026-06-03 feat(storage): adiciona rotinas de teste local em C para NVS e SPIFFS
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2026-06-03 feat( firmware odometria): codigos e headers e esqueleto de funcao main para teste
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2026-06-03 adicao de funcao main p/ teste de motores + correcao de erros
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2026-06-03 chore(storage): adiciona tabela de particoes customizada para SPIFFS e configura build
    [partitions.csv]
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2026-06-04 docs(relatorio): adicao do texto associando as HU com o que foi implementado (#118)
2026-06-04 ci: exporta evidencias de cobertura (artefatos + resumo no painel)
    Adiciona, em cada job do CI, a exportacao de evidencias da Tarefa T16 (#133):
    - backend: gera relatorio HTML/XML de cobertura e publica resumo no painel
    - frontend: publica resumo de cobertura no painel e exporta o relatorio HTML
    - e2e: exporta o relatorio do Playwright
    Os relatorios ficam disponiveis como artefatos baixaveis de cada execucao e
    o resumo de cobertura aparece na pagina da run, servindo de evidencia para a
    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
2026-06-04 docs(relatorio): redige secoes 7.5 e 7.6 do capitulo de V&V
    Escreve as secoes 7.5 (Testes de software) e 7.6 (Testes de integracao),
    consolidando os insumos das tarefas de teste:
    - 7.5: historias de usuario implementadas (tabela de associacao com prototipos
    e GUI), suites unitario/integracao com cobertura >=70% (backend 98%, frontend
    93%) e testes de sistema E2E.
    - 7.6: integracao do fluxo de telemetria validada com dados simulados,
    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
2026-06-04 docs(relatorio): comenta inclusao do anexo nao utilizado
    O anexo (12_anexos) ainda nao possui conteudo; comenta o \input para evitar
    uma entrada fantasma na lista de figuras.
2026-06-04 docs(relatorio): ajusta largura das colunas da Tabela 19
    Alarga a primeira coluna da tabela de testes de integracao para acomodar os
    nomes de arquivo em monospace (telemetria.spec.js, reconexao.spec.js) sem
    estourar a margem.
2026-06-04 adicao de mais uma funcao main de teste e correcao de erros
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2026-06-06 chore(firmware): ignora artefatos de build do ESP-IDF
    Adiciona src/firmware/.gitignore (build/, managed_components/, CMake e binarios .bin/.elf/.map) e remove do versionamento os diretorios build/ ja commitados nos projetos de teste de motores. Reduz ~5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
2026-06-10 docs: corrige o cronograma da parte de software
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2026-06-25 varias solucoes de bugs na implementacao dos IRs e adicionando alguns comentarios
    [infrared.c, infrared.h, m_driver.h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]
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2026-06-29 correcoes de bugs
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2026-07-08 fix(navegacao): corrige PD da reta e a curva de 90 graus
    Reta (movimentacao_move_cell):
    - Erro de alinhamento agora em cm (antes em metros). O encoder devolve
    deslocamento em metros (~0,0107 m/pulso); com os ganhos em escala de
    metros a correcao (int) era truncada para 0 e o PD nao atuava.
    - Correcao arredondada (lroundf) em vez de truncada.
    - Zera os encoders no inicio da celula (descarta pulsos residuais).
    Curva (movimentacao_turn_clws/ctclws):
    - Unifica as duas curvas numa rotina P com perfil trapezoidal: arranca em
    PWM 50 (vence o atrito estatico), desacelera ate um piso de 30 e para com
    margem angular para compensar a inercia, reduzindo overshoot/undershoot.
    - Zera os encoders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
    [movimentacao.c]
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2026-07-08 adiciona arquivos de estrutura
    [Chao.CATPart, Labirinto.CATProduct, MeioChao.CATPart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]
2026-07-09 adiciona novos arquivos CAD e remove arquivo obsoleto
    [2andar.CATPart, Chassi.CATPart, Product6.CATProduct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]
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
